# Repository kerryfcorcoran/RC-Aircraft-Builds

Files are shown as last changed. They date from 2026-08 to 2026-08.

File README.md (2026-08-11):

# RC Aircraft Builds

A public engineering archive for the design, construction, configuration, manufacturing, testing, and continued development of #teamcorc RC aircraft projects.

GitHub Pages:

https://teamcorc.github.io/RC-Aircraft-Builds/

This repository is intentionally organized as an engineering record rather than a conventional build blog. The goal is to preserve enough information to understand how each aircraft was actually constructed and configured at a particular point in its development.

---

## Repository Organization

Aircraft documentation follows this hierarchy:

```text
Manufacturer
└── Aircraft Model / Family
    └── Version
        └── Physical Build
```

This keeps different manufacturers, aircraft families, design revisions, and physical aircraft isolated from one another.

Current manufacturer areas include:

- Flightory
- Eclipson
- Titan Dynamics
- Additional manufacturers may be added as projects begin.

Example:

```text
aircraft/
├── flightory/
│   ├── stallion/
│   │   ├── references/
│   │   ├── v1/
│   │   │   └── build-01/
│   │   └── v2/
│   │       └── build-01/
│   ├── super-stingray-vtol/
│   ├── talon-1400/
│   └── stork/
├── eclipson/
└── titan-dynamics/
```

---

## Build-Level Engineering Records

A physical build can contain some or all of the following:

```text
build-01/
├── components/
├── assembly-wiring/
├── ardupilot/
├── flight-testing/
├── engineering/
├── media/
├── downloads/
└── printing/
```

Not every aircraft or build will contain every section. Documentation reflects information actually captured for that physical aircraft.

Typical records include:

- Exact installed hardware
- Component sources and manufacturer documentation
- Firmware
- ArduPilot PARAM files and configuration baselines
- Serial/UART mapping
- Servo and motor output assignments
- Wiring and power topology
- Assembly procedures and modifications
- 3D-printing/manufacturing settings
- Modified/custom STL files
- Ready-to-fly weight and battery configuration
- Flight-test objectives and observations
- Flight videos
- ArduPilot BIN logs
- Engineering analysis
- Configuration changes
- Known issues
- Lessons learned and build-specific gotchas

The intent is **reproducibility, configuration control, and traceability**.

---

# Flightory Stallion

The Stallion family currently contains two separate physical aircraft projects:

```text
Stallion
├── References
├── V1
│   └── Build 01
└── V2
    └── Build 01
```

## Stallion References

Family-level documentation is maintained under:

```text
aircraft/flightory/stallion/references/
```

This area contains:

- Official Flightory Stallion documentation
- Official Stallion VTOL documentation
- Matek F765-Wing references
- Builder Notes — Lessons Learned & Gotchas

Family-level references are intentionally separate from configuration records belonging to a specific physical aircraft.

Where a lesson applies only to one version/build, it should be explicitly identified as such.

---

## Stallion VTOL V1 — Build 01

V1 Build 01 is an existing aircraft undergoing VTOL flight development and testing.

The V1 record includes aircraft configuration, ArduPilot information, flight testing, engineering analysis, media, and downloadable configuration artifacts.

Detailed original manufacturing information was not captured during construction, so V1 Build 01 intentionally does **not** contain a 3D Printing & Manufacturing section.

Current hover/test configuration documented by the project:

- Ready-to-fly AUW: **2150 g**
- Hover/test battery: **4S 4200 mAh LiPo**
- Flight controller: **Matek F765-Wing**
- Firmware: **ArduPlane 4.6.3**

A separate 4S4P 14,000 mAh Li-ion battery is available as an endurance option but is not the current hover-test configuration.

---

## Stallion VTOL V2 — Build 01

V2 Build 01 is the newer Stallion build and contains substantially more detailed manufacturing and construction records.

Current implemented sections include:

- **3D Printing & Manufacturing**
- **Components**
- **Assembly & Wiring**
- **Downloads**
- **Builder Notes / reference material**

Additional sections will be populated as the build progresses.

### 3D Printing & Manufacturing

The detailed manufacturing report is located at:

```text
aircraft/flightory/stallion/v2/build-01/printing/
```

The report preserves part-level information such as:

- Printer
- Material
- Slicer
- Key slicer settings
- Print time
- Filament usage
- Part weight
- Status
- Reprints
- Build-specific findings

Current slicer baseline includes **OrcaSlicer v2.4.2**.

### Key V2 Manufacturing Findings

#### Thin-Wall Parts

The following parts can be sliced successfully in OrcaSlicer and do not require Cura:

- BOOM TAIL INSERT
- BOOM FUS INSERT
- BOOM FUS MOUNT

Required configuration:

- **Detect Thin Walls:** Enabled
- **Wall Generator:** Arachne

This supersedes the earlier interim finding that Cura was required for these parts.

#### X-Y Hole Compensation

For Stallion VTOL V2 Build 01, verify:

```text
X-Y Hole Compensation: 0.30 mm
```

This setting is part of the V2 Build 01 manufacturing baseline and should be checked when preparing applicable parts with holes or fitted hardware.

### Modified V-Tail Parts

Both VTail 1 components required modification during V2 Build 01 manufacturing:

- **V TAIL 1 L (modified)**
- **V TAIL 1 R (modified)**

The exact modified STL files are preserved under:

```text
aircraft/flightory/stallion/v2/build-01/downloads/
```

The corresponding part names in the 3D Printing & Manufacturing report link directly to these files.

The modified geometry is retained as a **build-specific configuration-controlled artifact** rather than replacing the original Flightory design reference.

### Components

V2 Build 01 component documentation is maintained under:

```text
aircraft/flightory/stallion/v2/build-01/components/
```

Current recorded hardware includes:

- **Torsion Springs — 4.5 mm, 120 Degree**

Component entries may include manufacturer documentation or product/source references where appropriate.

### Assembly & Wiring

V2 Build 01 assembly notes are maintained under:

```text
aircraft/flightory/stallion/v2/build-01/assembly-wiring/
```

A current build-specific wiring procedure is the V-tail servo extension:

- Cut the V-tail servo leads immediately behind the factory connector pins.
- Extend each lead by **400 mm** using matching servo wire.
- Maintain signal, positive-power, and ground conductor order/polarity.
- Insulate and strain-relieve the splices.
- Route the extended wiring through the carbon-fiber structure to the flight controller.

The 400 mm extension provides sufficient routing length without placing the servo wiring under unnecessary tension.

### Downloads

V2 Build 01 downloadable artifacts are stored under:

```text
aircraft/flightory/stallion/v2/build-01/downloads/
```

This area may contain:

- Modified/custom STL files
- PARAM/configuration files
- Engineering reports
- Other build-specific downloadable artifacts

Downloads should remain associated with the physical build to which they apply.

---

# Configuration Control Philosophy

Documentation should describe the aircraft **as it actually existed**, not simply the intended design.

When hardware, firmware, wiring, parameters, battery configuration, manufacturing geometry, or other significant items change, the engineering record should be updated accordingly.

Build-specific changes should not silently overwrite manufacturer references or records from another aircraft version.

Examples:

- A modified V2 STL belongs to the V2 Build 01 record.
- A V1 PARAM file belongs to V1 Build 01.
- A family-level Flightory manual belongs in Stallion References.
- A test-flight BIN should remain associated with the aircraft configuration that produced it.

---

# PARAM and Flight-Test Records

Meaningful ArduPilot configuration milestones should be preserved as named PARAM snapshots.

Examples include:

- Initial configuration
- Motor/servo verification
- First hover
- Roll/pitch tuning
- Yaw tuning
- First stable hover
- QLOITER preparation
- First successful QLOITER
- Pre-transition configuration
- Post-transition tuning

Meaningful flight tests should preserve the corresponding BIN log whenever possible.

BIN logs support quantitative evaluation of:

- PID tracking
- EKF behavior
- Yaw performance
- Motor saturation
- Magnetic interference
- RC input
- GPS behavior
- Battery behavior
- Flight-mode changes
- System messages

Video documents what the aircraft appeared to do; telemetry and BIN data help establish why it did it.

---

# Website

The repository is published as a static GitHub Pages project site.

Design goals include:

- Dark engineering-oriented theme
- Responsive layout
- Card-based navigation
- Clickable breadcrumb navigation
- Relative internal links wherever practical
- No server-side dependencies
- No unnecessary web frameworks

The repository remains a GitHub Pages **project site**:

```text
https://teamcorc.github.io/RC-Aircraft-Builds/
```

The repository should remain:

```text
teamcorc/RC-Aircraft-Builds
```

It should **not** be renamed to `teamcorc.github.io`.

---

# Documentation Standards

When adding or updating project records:

1. Preserve existing working content unless it is intentionally being revised.
2. Do not invent configuration, wiring, hardware, or test details.
3. Prefer official manufacturer documentation where available.
4. Keep different aircraft versions and physical builds isolated.
5. Preserve exact filenames for configuration-controlled artifacts.
6. Use relative internal links where practical.
7. Record actual test configuration, including AUW and battery when relevant.
8. Preserve meaningful PARAM and BIN records.
9. Treat modified files as build-specific artifacts unless their applicability has been independently established more broadly.
10. Add lessons learned and gotchas as they are discovered.

---

## Project Goal

The long-term goal of **RC Aircraft Builds** is to create a durable engineering archive that allows a future reader—or the builder months or years later—to determine:

- What was built
- Which hardware was installed
- How it was configured
- How it was manufactured
- What was changed
- What was tested
- What worked
- What did not work
- Why later decisions were made

That record is intended to remain useful long after an individual build or flight-test session is complete.

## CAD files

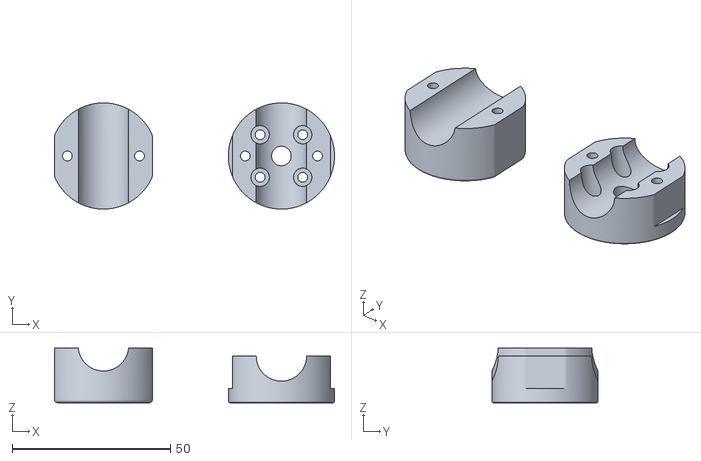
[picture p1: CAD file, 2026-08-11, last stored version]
Split Rear Motor Mount.stl
88.4 x 33.5 x 17.2

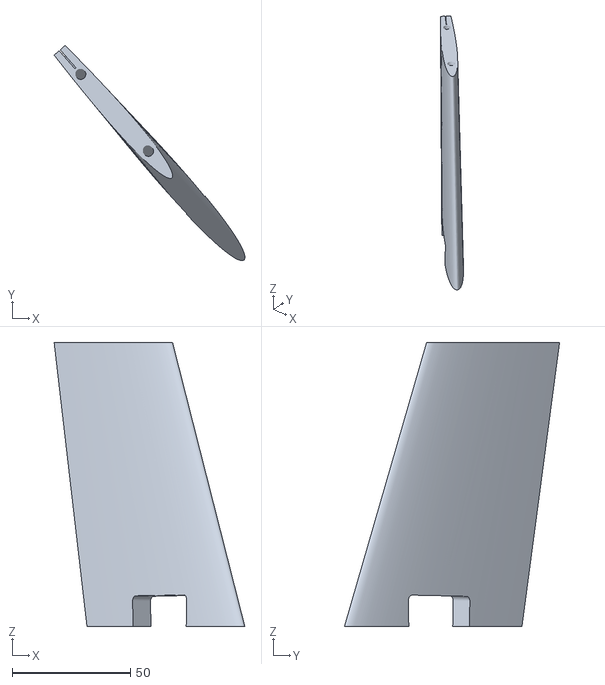
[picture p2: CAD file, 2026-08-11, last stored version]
VTail Right Modified.stl
80.6 x 90.9 x 120.0

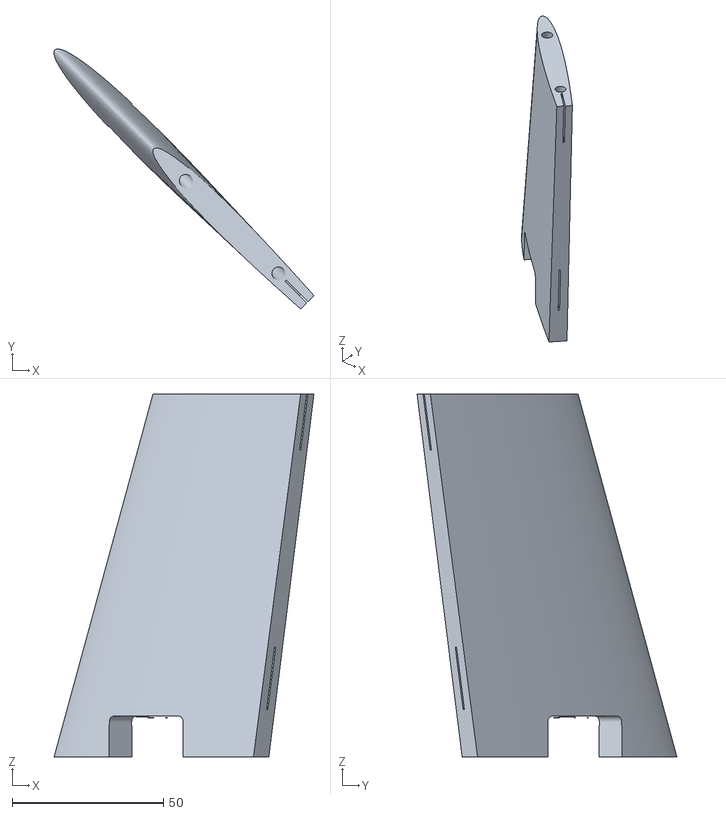
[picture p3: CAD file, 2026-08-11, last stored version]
VTail Left Modified.stl
85.9 x 85.9 x 120.0

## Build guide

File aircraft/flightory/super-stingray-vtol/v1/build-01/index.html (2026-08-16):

SUPER STINGRAY VTOL V1 — BUILD 01

Site HomeSuper Stingray VTOLV1

Home → Flightory → Super Stingray VTOL → V1 → Build 01

Physical Build 01

# Super Stingray VTOL V1 — Build 01

Build-specific engineering, manufacturing, configuration, and test documentation.

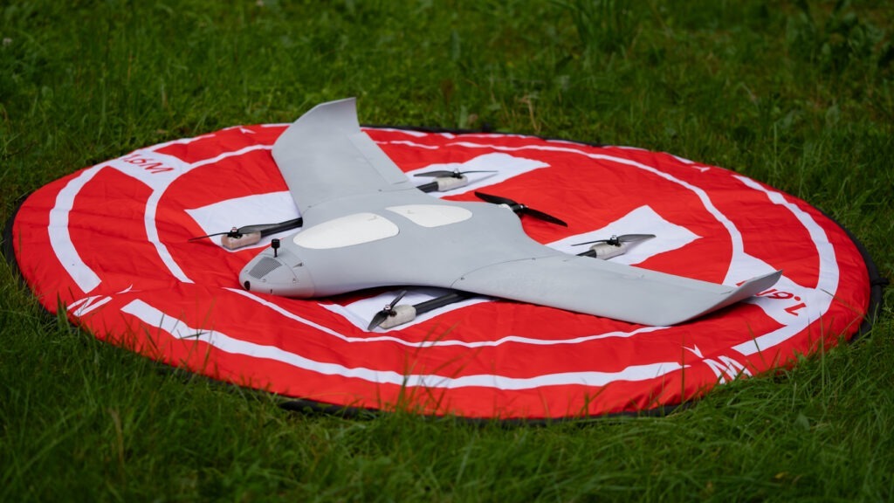
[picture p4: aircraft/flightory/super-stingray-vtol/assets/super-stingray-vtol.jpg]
Flightory Super Stingray VTOL aircraft


Image: Flightory

AVAILABLE

## 🖨️ 3D Printing & Manufacturing

Detailed part-level manufacturing report including printers, materials, slicer settings, weights, print times, filament consumption, and process notes.

Open Printing Report → AVAILABLE

## ✈️ Components

Installed and selected flight-control, propulsion-electronics, avionics, servos, batteries, and hardware.

Open Components →

## 🔧 Assembly & Wiring

Assembly procedures, wiring, connectors, and modifications.

SECTION TO BUILD

## 🛩️ ArduPilot

Firmware, parameters, configuration, calibration, and baselines.

SECTION TO BUILD

## 📊 Flight Testing

Ground tests, hover tests, flight tests, and video.

SECTION TO BUILD

AVAILABLE

## 📷 Media

Super Stingray and VTOL manuals, official Flightory documentation, and Matek F405-Wing reference material.

Open Media →

## 📁 Downloads

Build-specific downloadable artifacts.

SECTION TO BUILD

RC Aircraft Builds · Engineering Documentation

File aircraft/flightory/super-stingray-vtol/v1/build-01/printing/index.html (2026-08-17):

SUPER STINGRAY VTOL V1 — BUILD 01

RC Aircraft Builds Flightory Super Stingray VTOL V1 Build 01 3D Printing

RC Aircraft Builds → Flightory → Super Stingray VTOL → V1 → Build 01 → 3D Printing

#teamcorc · Super Stingray VTOL V1 Manufacturing

Flightory Super Stingray VTOL aircraft

Image: Flightory

# Detailed 3D Printing Report

Production report with executive summary, material usage, section-by-section part details, printer assignments, slicer settings, individual weights, print times, filament consumption, and reprint/process history.

37

Accepted printed components

689 g

Known accepted printed-part mass

254.210 m

Known filament consumed

73h 50m

Known recorded print time

Totals reflect accepted, recorded prints only.

Expand all Collapse all

### Material Summary

Material Group | Weight | Filament | Time
Overture PETG ↗ (https://overture3d.com/products/overture-petg) — Red | 260 g | 89.240 m | 9h 45m
eSun ePLA-LW ↗ (https://esun3dstore.com/products/epla-lw) — White | 429 g | 164.970 m | 64h 05m
Total | 689 g | 254.210 m | 73h 50m

Figures are printed-component mass only, not final empty weight or AUW.

### Current Process Baseline

Primary slicer: OrcaSlicer v2.4.2 ↗ (https://github.com/OrcaSlicer/OrcaSlicer/releases/tag/v2.4.2)

Nozzle: Creality Unicorn Hardened Steel Nozzle — 0.4 mm ↗ (https://store.creality.com/products/unicorn-quick-swap-nozzle-kit-for-k1c-ender-3-v3).

Structural PETG parts: 20% Cubic infill; generally 3 walls, with selected parts using 2 walls as recorded in the component tables. Supports used where required by geometry.

Lightweight ePLA-LW parts: Printed on either K1-Max White or K1-Max Orange as recorded in the component tables; generally 1 wall with 3% Gyroid infill and 45° orientation, with selected parts such as NOSE using 2 walls as recorded.

Boom / Tail Assembly 2 accepted line items · 46.0 g · 17.290 m · 1h 54m ▼

Part | Printer | Material | Slicer | Key Settings | Weight | Time | Filament | Status | Notes
BOOM MOUNT L | K1-Max Orange | Overture PETG ↗ (https://overture3d.com/products/overture-petg) Red | OrcaSlicer v2.4.2 | 3 walls; 20% Cubic; supports | 23 g | 1h 05m | 9.710 m | Complete
BOOM MOUNT R | K1-Max Orange | Overture PETG ↗ (https://overture3d.com/products/overture-petg) Red | OrcaSlicer v2.4.2 | 3 walls; 20% Cubic; no supports | 23 g | 49 m | 7.580 m | Complete | Fine without supports

Powertrain / Motor Mounts 3 line items · 9 accepted units · TOP ×4 · BOTTOM ×4 · MOTOR MOUNT ×1 complete ▼

Part | Qty | Printer | Material | Slicer | Key Settings | Weight | Time | Filament | Status | Notes
MOTOR MOUNT BOTTOM VTOL | 4 | K1-Max Orange | Overture PETG ↗ (https://overture3d.com/products/overture-petg) Red | OrcaSlicer v2.4.2 | 3 walls; 20% Cubic | 10 g | 24 m | 3.400 m | Complete | Per-unit figures
MOTOR MOUNT TOP VTOL | 4 | K1-Max Orange | Overture PETG ↗ (https://overture3d.com/products/overture-petg) Red | OrcaSlicer v2.4.2 | 3 walls; 20% Cubic | 8 g | 21 m | 2.740 m | Complete | Per-unit figures
MOTOR MOUNT | 1 | K1-Max Orange | Overture PETG ↗ (https://overture3d.com/products/overture-petg) Red | OrcaSlicer v2.4.2 | 2 walls; 20% Cubic | 6 g | 23 m | 1.960 m | Complete

Wings 14 accepted line items · 271.0 g · 99.720 m · 29h 22m ▼

Part | Printer | Material | Slicer | Key Settings | Weight | Time | Filament | Status | Notes
WING ROOT VTOL L | K1-Max Orange | Overture PETG ↗ (https://overture3d.com/products/overture-petg) Red | OrcaSlicer v2.4.2 | 3 walls; 20% Cubic; no supports | 47 g | 1h 15m | 15.670 m | Complete
WING ROOT VTOL R | K1-Max Orange | Overture PETG ↗ (https://overture3d.com/products/overture-petg) Red | OrcaSlicer v2.4.2 | 3 walls; 20% Cubic; no supports | 47 g | 1h 15m | 15.670 m | Complete
WING 2 L | K1-Max White | eSun ePLA-LW ↗ (https://esun3dstore.com/products/epla-lw) White | OrcaSlicer v2.4.2 | 1 wall; 3% Gyroid; 45° orientation | 24 g | 3h 08m | 8.590 m | Complete
WING 2 R VTOL | K1-Max White | eSun ePLA-LW ↗ (https://esun3dstore.com/products/epla-lw) White | OrcaSlicer v2.4.2 | 1 wall; 3% Gyroid; 45° orientation | 23 g | 2h 46m | 8.380 m | Complete
WINGTIP L 1 | K1-Max White | eSun ePLA-LW ↗ (https://esun3dstore.com/products/epla-lw) White | OrcaSlicer v2.4.2 | 1 wall; 3% Gyroid; 45° orientation | 11 g | 1h 26m | 4.210 m | Complete
WINGTIP L 2 | K1-Max White | eSun ePLA-LW ↗ (https://esun3dstore.com/products/epla-lw) White | OrcaSlicer v2.4.2 | 1 wall; 3% Gyroid; 45° orientation | 7 g | 56 m | 2.570 m | Complete
WINGTIP R 1 | K1-Max White | eSun ePLA-LW ↗ (https://esun3dstore.com/products/epla-lw) White | OrcaSlicer v2.4.2 | 1 wall; 3% Gyroid; 45° orientation | 12 g | 1h 26m | 4.220 m | Complete
WINGTIP R 2 | K1-Max Orange | eSun ePLA-LW ↗ (https://esun3dstore.com/products/epla-lw) White | OrcaSlicer v2.4.2 | 1 wall; 3% Gyroid; 45° orientation | 6 g | 56 m | 2.580 m | Complete
WING 1 L | K1-Max White | eSun ePLA-LW ↗ (https://esun3dstore.com/products/epla-lw) White | OrcaSlicer v2.4.2 | 1 wall; 3% Gyroid; 45° orientation | 39 g | 6h 07m | 15.170 m | Complete
WING 1 R | K1-Max Orange | eSun ePLA-LW ↗ (https://esun3dstore.com/products/epla-lw) White | OrcaSlicer v2.4.2 | 1 wall; 3% Gyroid; 45° orientation | 36 g | 6h 09m | 15.160 m | Complete
AILERON 1L VTOL | K1-Max Orange | eSun ePLA-LW ↗ (https://esun3dstore.com/products/epla-lw) White | OrcaSlicer v2.4.2 | 1 wall; 3% Gyroid; 45° orientation | 5 g | 54 m | 1.710 m | Complete
AILERON 1R VTOL | K1-Max White | eSun ePLA-LW ↗ (https://esun3dstore.com/products/epla-lw) White | OrcaSlicer v2.4.2 | 1 wall; 3% Gyroid; 45° orientation | 4 g | 54 m | 1.670 m | Complete
AILERON 2L VTOL | K1-Max Orange | eSun ePLA-LW ↗ (https://esun3dstore.com/products/epla-lw) White | OrcaSlicer v2.4.2 | 1 wall; 3% Gyroid; 45° orientation | 5 g | 1h 05m | 2.080 m | Complete
AILERON 2R VTOL | K1-Max White | eSun ePLA-LW ↗ (https://esun3dstore.com/products/epla-lw) White | OrcaSlicer v2.4.2 | 1 wall; 3% Gyroid; 45° orientation | 5 g | 1h 05m | 2.040 m | Complete

Fuselage 12 accepted line items · 294.0 g · 110.680 m · 39h 11m ▼

Part | Printer | Material | Slicer | Key Settings | Weight | Time | Filament | Status | Notes
FUS ROOT L | K1-Max Orange | Overture PETG ↗ (https://overture3d.com/products/overture-petg) Red | OrcaSlicer v2.4.2 | 3 walls; 20% Cubic | 9 g | 28 m | 2.870 m | Complete
FUS ROOT R | K1-Max Orange | Overture PETG ↗ (https://overture3d.com/products/overture-petg) Red | OrcaSlicer v2.4.2 | 3 walls; 20% Cubic | 8 g | 28 m | 2.880 m | Complete
BATTERY PAD | K1-Max Orange | Overture PETG ↗ (https://overture3d.com/products/overture-petg) Red | OrcaSlicer v2.4.2 | 2 walls; 20% Cubic | 20 g | 48 m | 6.640 m | Complete
FRONT REINFORCEMENT | K1-Max Orange | Overture PETG ↗ (https://overture3d.com/products/overture-petg) Red | OrcaSlicer v2.4.2 | 2 walls; 20% Cubic | 5 g | 14 m | 1.700 m | Complete
FUS 1 | K1-Max White | eSun ePLA-LW ↗ (https://esun3dstore.com/products/epla-lw) White | OrcaSlicer v2.4.2 | 1 wall; 3% Gyroid; 45° orientation | 33 g | 4h 21m | 12.120 m | Complete
FUS 4 L | K1-Max White | eSun ePLA-LW ↗ (https://esun3dstore.com/products/epla-lw) White | OrcaSlicer v2.4.2 | 1 wall; 3% Gyroid; 45° orientation; supports | 13 g | 2h 04m | 4.770 m | Complete | Uses supports, unlike other ePLA-LW parts
FUS 4 R | K1-Max White | eSun ePLA-LW ↗ (https://esun3dstore.com/products/epla-lw) White | OrcaSlicer v2.4.2 | 1 wall; 3% Gyroid; 45° orientation; supports | 13 g | 2h 05m | 4.860 m | Complete | Uses supports, unlike other ePLA-LW parts
NOSE | K1-Max White | eSun ePLA-LW ↗ (https://esun3dstore.com/products/epla-lw) White | OrcaSlicer v2.4.2 | 2 walls; 3% Gyroid; 45° orientation | 27 g | 3h 45m | 9.940 m | Complete | 2 walls — differs from 1-wall standard on other ePLA-LW parts
FUS 2 L | K1-Max White | eSun ePLA-LW ↗ (https://esun3dstore.com/products/epla-lw) White | OrcaSlicer v2.4.2 | 1 wall; 3% Gyroid; 45° orientation | 29 g | 4h 05m | 11.170 m | Complete
FUS 2 R | K1-Max Orange | eSun ePLA-LW ↗ (https://esun3dstore.com/products/epla-lw) White | OrcaSlicer v2.4.2 | 1 wall; 3% Gyroid; 45° orientation | 27 g | 4h 04m | 11.140 m | Complete
FUS 3 R | K1-Max Orange | eSun ePLA-LW ↗ (https://esun3dstore.com/products/epla-lw) White | OrcaSlicer v2.4.2 | 1 wall; 3% Gyroid; 45° orientation | 52 g | 8h 50m | 21.360 m | Complete
FUS 3 L | K1-Max White | eSun ePLA-LW ↗ (https://esun3dstore.com/products/epla-lw) White | OrcaSlicer v2.4.2 | 1 wall; 3% Gyroid; 45° orientation | 58 g | 7h 59m | 21.230 m | Complete

Manufacturing Baseline ▼

## Manufacturing Baseline

37 accepted components · 689 g known mass · 254.210 m known filament · 73h 50m known printing

Boom/tail hardware, powertrain motor mounts (MOTOR MOUNT TOP VTOL ×4, MOTOR MOUNT BOTTOM VTOL ×4, MOTOR MOUNT ×1), wing roots, WING 1 L/R, WING 2 L/R, WINGTIP L 1/2, WINGTIP R 1/2, AILERON 1L/1R/2L/2R VTOL, and fuselage hardware (FUS ROOT L/R, BATTERY PAD, FRONT REINFORCEMENT, FUS 1, FUS 4 L, FUS 4 R, NOSE, FUS 2 L/R, FUS 3 L/R) all complete. All recorded completed parts printed clean without supports except BOOM MOUNT L, FUS 4 L, and FUS 4 R (supports). WING 1 L/R, WING 2 L/R, all wingtips and ailerons, and the FUS 1/2/3/4 series plus NOSE run the second process: eSun ePLA-LW at 1 wall / 3% Gyroid / 45° orientation (NOSE uses 2 walls), printed on K1-Max White or K1-Max Orange as recorded in the component tables.

Super Stingray VTOL V1 — Detailed 3D Printing Manufacturing Report · Slicing baseline: OrcaSlicer v2.4.2 (https://github.com/OrcaSlicer/OrcaSlicer/releases/tag/v2.4.2)

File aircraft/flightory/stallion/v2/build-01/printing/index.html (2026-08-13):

STALLION VTOL V2 — BUILD 01

RC Aircraft Builds Flightory Stallion V2 Build 01 3D Printing

RC Aircraft Builds → Flightory → Stallion → V2 → Build 01 → 3D Printing

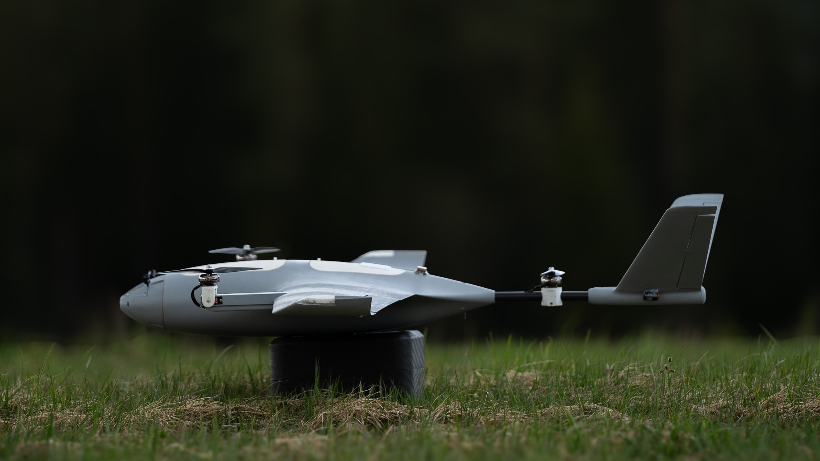
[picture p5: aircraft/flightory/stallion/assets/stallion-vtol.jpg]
Flightory Stallion VTOL aircraft
#teamcorc · Stallion VTOL V2 Manufacturing 

Image: Flightory

# Detailed 3D Printing Report

Refreshed production report with executive summary, material usage, section-by-section part details, printer assignments, slicer settings, individual weights, print times, filament consumption, and reprint/process history.

66

Accepted printed components

883 g*

Known accepted printed-part mass

412.090 m*

Known filament consumed

91h 08m*

Known recorded print time

* Split Rear Motor Mount is accepted, but its weight, print time, and filament usage have not yet been recorded; aggregate known totals exclude those values.

Expand all Collapse all

### Material Summary

Material Group | Weight | Filament | Time
Polymaker PolyLite LW-PLA ↗ (https://us.polymaker.com/products/polylite-lw-pla) — Gray / White | 650 g | 321.225 m* | 65 h 54 m*
Overture PETG ↗ (https://overture3d.com/products/overture-petg) — White / Red | 232 g* | 90.516 m* | 25 h 07 m*
Generic PLA — Transparent | 1 g | 0.349 m | 7 m
Total | 883 g* | 412.090 m* | 91 h 08 m*

The 895 g figure is printed-component mass only, not final empty weight or AUW. *Tail 1 print time and filament were not recorded, so filament/time totals are known minimums.

### Current Process Baseline

Primary slicer: OrcaSlicer v2.4.2 ↗ (https://github.com/OrcaSlicer/OrcaSlicer/releases/tag/v2.4.2)

Nozzle: Creality Unicorn Hardened Steel Nozzle — 0.4 mm ↗ (https://store.creality.com/products/unicorn-quick-swap-nozzle-kit-for-k1c-ender-3-v3).

LW-PLA aerodynamic parts: primarily OrcaSlicer with 1 wall and low-density Gyroid or Lateral Lattice infill.

Structural PETG: generally 3 walls with 20% Grid or Cubic depending on part.

Thin-wall boom parts: OrcaSlicer works correctly when Detect Thin Walls is enabled and Wall Generator = Arachne.

Transparent LED covers: Detect Thin Walls enabled.

Key Manufacturing Findings Updated to reflect the latest validated slicer configuration ▼

### OrcaSlicer v2.4.2 ↗ (https://github.com/OrcaSlicer/OrcaSlicer/releases/tag/v2.4.2) — Thin-Wall Configuration

BOOM TAIL INSERT, BOOM FUS INSERT, and BOOM FUS MOUNT do not require Cura. They can be sliced successfully in OrcaSlicer with:

- Detect Thin Walls: Enabled
- Wall Generator: Arachne

This supersedes the earlier interim note that Cura was required.

### X-Y Hole Compensation

For Stallion VTOL V2 Build 01, ensure X-Y Hole Compensation is set to 0.30 mm in OrcaSlicer before slicing applicable parts.

This is part of the V2 Build 01 manufacturing baseline and should be checked when preparing parts with holes or fitted hardware.

### Replacement / Reprint Notes

- Custom rear motor mount: original split; replacement uses separate Top-Rear-Motor-Mount and Bottom-Rear-Motor-Mount parts.
- TAIL 1: accepted as final part (18 g); print time and filament were not recorded.
- Wing Lock Assembly: Neptune 2S Base + Front L/R + Rear L/R assembly accepted as final.

Wings 10 accepted line items · 219.0 g recorded · 110.919 m recorded · 22h 16m recorded ▼

Part | Printer | Material | Slicer | Key Settings | Weight | Time | Filament | Status | Notes
WING 3 R | K1 Max Orange | Polymaker PolyLite LW-PLA ↗ (https://us.polymaker.com/products/polylite-lw-pla) Gray | OrcaSlicer | 1 wall; 3% Lateral Lattice; 45° | 23 g | 2h 15m | 11.300 m | Complete | Minimal post cleanup
WING 3 L | K1 Max White | Polymaker PolyLite LW-PLA ↗ (https://us.polymaker.com/products/polylite-lw-pla) Gray | OrcaSlicer | 1 wall; 3% Lateral Lattice; 45° | 23 g | 2h 15m | 11.300 m | Complete
WING 1R VTOL | K1 Max Orange | Polymaker PolyLite LW-PLA ↗ (https://us.polymaker.com/products/polylite-lw-pla) Gray | OrcaSlicer | 1 wall; 3% Lateral Lattice; 45° | 45 g | 4h 29m | 22.400 m | Complete
WING 1L VTOL | K1 Max White | Polymaker PolyLite LW-PLA ↗ (https://us.polymaker.com/products/polylite-lw-pla) Gray | OrcaSlicer | 1 wall; 3% Lateral Lattice; 45°; supports | 45 g | 4h 38m | 23.050 m | Complete | Support test came out very clean
WING 2L VTOL | K1 Max White | Polymaker PolyLite LW-PLA ↗ (https://us.polymaker.com/products/polylite-lw-pla) Gray | OrcaSlicer | 1 wall; 3% Lateral Lattice; 45°; tree support auto | 26 g | 2h 50m | 14.000 m | Complete
WING 2R VTOL | K1 Max Orange | Polymaker PolyLite LW-PLA ↗ (https://us.polymaker.com/products/polylite-lw-pla) Gray | OrcaSlicer | 1 wall; 3% Lateral Lattice; 45°; tree support auto | 27 g | 2h 51m | 14.040 m | Complete
WINGTIP R LED | K1 Max Orange | Polymaker PolyLite LW-PLA ↗ (https://us.polymaker.com/products/polylite-lw-pla) Gray | OrcaSlicer | 1 wall; 3% Lateral Lattice; 45° | 15 g | 1h 25m | 7.240 m | Complete
WINGTIP L LED | K1 Max Orange | Polymaker PolyLite LW-PLA ↗ (https://us.polymaker.com/products/polylite-lw-pla) Gray | OrcaSlicer | 1 wall; 3% Lateral Lattice; 45° | 14 g | 1h 26m | 7.240 m | Complete
WING LED COVER L | K1 Max White | Generic PLA Transparent | OrcaSlicer | Detect Thin Walls | 0.5 g | 3.5 min | 0.174 m | Complete | Printed as shared L/R job; job total 7 min / 0.349 m
WING LED COVER R | K1 Max White | Generic PLA Transparent | OrcaSlicer | Detect Thin Walls | 0.5 g | 3.5 min | 0.174 m | Complete | Printed as shared L/R job; job total 7 min / 0.349 m

Fuselage 11 accepted line items · 306.0 g recorded · 153.116 m recorded · 29h 27m recorded ▼

Part | Printer | Material | Slicer | Key Settings | Weight | Time | Filament | Status | Notes
FUS 1 | K1 Max White | Polymaker PolyLite LW-PLA ↗ (https://us.polymaker.com/products/polylite-lw-pla) Gray | OrcaSlicer | 1 wall; 3% Gyroid; 0° | 33 g | 3h 09m | 16.410 m | Complete
FUS 2 | K1 Max White | Polymaker PolyLite LW-PLA ↗ (https://us.polymaker.com/products/polylite-lw-pla) Gray | OrcaSlicer | 1 wall; 3% Gyroid; 45°; support enabled | 51 g | 4h 45m | 25.440 m | Complete
FUS 3 | K1 Max Orange | Polymaker PolyLite LW-PLA ↗ (https://us.polymaker.com/products/polylite-lw-pla) Gray | OrcaSlicer | 1 wall; 3% Gyroid; 45° | 51 g | 4h 54m | 25.660 m | Complete
FUS 4 | K1 Max White | Polymaker PolyLite LW-PLA ↗ (https://us.polymaker.com/products/polylite-lw-pla) Gray | OrcaSlicer | 1 wall; 3% Gyroid; 45° | 70 g | 7h 02m | 37.726 m | Complete
FUS 5 | K1 Max Orange | Polymaker PolyLite LW-PLA ↗ (https://us.polymaker.com/products/polylite-lw-pla) Gray | OrcaSlicer | 1 wall; 3% Gyroid; 45° | 39 g | 3h 36m | 18.720 m | Complete
HATCH FRONT 1 | K1 Max White | Polymaker PolyLite LW-PLA ↗ (https://us.polymaker.com/products/polylite-lw-pla) White | OrcaSlicer | 1 wall; 3% Gyroid; 45° | 7 g | 48m | 3.320 m | Complete
HATCH FRONT 2 | K1 Max White | Polymaker PolyLite LW-PLA ↗ (https://us.polymaker.com/products/polylite-lw-pla) White | OrcaSlicer | 1 wall; 3% Gyroid; 45° | 8 g | 49m | 3.670 m | Complete
HATCH REAR 1 | K1 Max Orange | Polymaker PolyLite LW-PLA ↗ (https://us.polymaker.com/products/polylite-lw-pla) White | OrcaSlicer | 1 wall; 3% Gyroid; 45° | 7 g | 43m | 3.270 m | Complete | Printer assignment corrected from White to Orange
HATCH REAR 2 | K1 Max Orange | Polymaker PolyLite LW-PLA ↗ (https://us.polymaker.com/products/polylite-lw-pla) White | OrcaSlicer | 1 wall; 3% Gyroid; 45° | 6 g | 42m | 2.810 m | Complete
NOSE | K1 Max Orange | Polymaker PolyLite LW-PLA ↗ (https://us.polymaker.com/products/polylite-lw-pla) Gray | OrcaSlicer | 2 walls; 3% Gyroid; 45° | 29 g | 2h 24m | 13.610 m | Complete | Weight supplied later
NOSE TOP | K1 Max White | Polymaker PolyLite LW-PLA ↗ (https://us.polymaker.com/products/polylite-lw-pla) White | OrcaSlicer | 2 walls; 3% Gyroid; 45° | 5 g | 35m | 2.480 m | Complete

Tail & Control Surfaces 16 accepted line items · 108.0 g recorded · 57.539 m recorded · 14h 02m recorded ▼

Part | Printer | Material | Slicer | Key Settings | Weight | Time | Filament | Status | Notes
V TAIL 1 L (modified) ⬇ | K1 Max Orange | Polymaker PolyLite LW-PLA ↗ (https://us.polymaker.com/products/polylite-lw-pla) Gray | OrcaSlicer | 4% Gyroid; 45°; support | 14 g | 1h 32m | 7.220 m | Complete | Modified for V2 Build 01. Click part name to download the modified STL.
V TAIL 1 R (modified) ⬇ | K1 Max White | Polymaker PolyLite LW-PLA ↗ (https://us.polymaker.com/products/polylite-lw-pla) Gray | OrcaSlicer | 4% Gyroid; 45°; support | 12 g | 1h 32m | 7.210 m | Complete | Modified for V2 Build 01. Click part name to download the modified STL.
V TAIL 2 L | K1 Max Orange | Polymaker PolyLite LW-PLA ↗ (https://us.polymaker.com/products/polylite-lw-pla) Gray | OrcaSlicer | 4% Gyroid; 45°; support | 9 g | 1h 07m | 4.700 m | Complete
V TAIL 2 R | K1 Max White | Polymaker PolyLite LW-PLA ↗ (https://us.polymaker.com/products/polylite-lw-pla) Gray | OrcaSlicer | 4% Gyroid; 45°; support | 8 g | 1h 07m | 4.710 m | Complete
V TAIL TIP L | K1 Max Orange | Polymaker PolyLite LW-PLA ↗ (https://us.polymaker.com/products/polylite-lw-pla) Gray | OrcaSlicer | 4% Gyroid; 45° | 0.5 g | 13m | 0.877 m | Complete
V TAIL TIP R | K1 Max White | Polymaker PolyLite LW-PLA ↗ (https://us.polymaker.com/products/polylite-lw-pla) Gray | OrcaSlicer | 4% Gyroid; 45° | 0.5 g | 13m | 0.852 m | Complete
RUDDER 1L | K1 Max Orange | Polymaker PolyLite LW-PLA ↗ (https://us.polymaker.com/products/polylite-lw-pla) Gray | OrcaSlicer | 4% Gyroid; 45° | 6 g | 52m | 2.570 m | Complete
RUDDER 1R | K1 Max White | Polymaker PolyLite LW-PLA ↗ (https://us.polymaker.com/products/polylite-lw-pla) Gray | OrcaSlicer | 4% Gyroid; 45° | 6 g | 52m | 2.570 m | Complete
RUDDER 2L | K1 Max Orange | Polymaker PolyLite LW-PLA ↗ (https://us.polymaker.com/products/polylite-lw-pla) Gray | OrcaSlicer | 4% Gyroid; 45° | 3 g | 38m | 1.660 m | Complete
RUDDER 2R | K1 Max White | Polymaker PolyLite LW-PLA ↗ (https://us.polymaker.com/products/polylite-lw-pla) Gray | OrcaSlicer | 4% Gyroid; 45° | 3 g | 38m | 1.660 m | Complete
TAIL 1 | K1 Max White | Polymaker PolyLite LW-PLA ↗ (https://us.polymaker.com/products/polylite-lw-pla) Gray | OrcaSlicer | 2 walls; 3% Gyroid | 18 g | — | — | Complete | Accepted final part; print time and filament were not recorded
TAIL 2 | K1 Max Orange | Polymaker PolyLite LW-PLA ↗ (https://us.polymaker.com/products/polylite-lw-pla) Gray | OrcaSlicer | 2 walls; 3% Gyroid; painted tree support | 18 g | 1h 38m | 8.870 m | Complete
TAIL 3 | Not recorded | Not recorded | Not recorded | | 2 g | 14m | 1.190 m | Complete
AILERON 1L | K1 Max Orange | Polymaker PolyLite LW-PLA ↗ (https://us.polymaker.com/products/polylite-lw-pla) Gray | OrcaSlicer | 1 wall; 3% Gyroid; 45° | 7 g | 50m | 3.300 m | Complete
AILERON 1R | K1 Max White | Polymaker PolyLite LW-PLA ↗ (https://us.polymaker.com/products/polylite-lw-pla) Gray | OrcaSlicer | 1 wall; 3% Gyroid; 45° | 6 g | 51m | 3.300 m | Complete
AILERON 2L | K1 Max Orange | Polymaker PolyLite LW-PLA ↗ (https://us.polymaker.com/products/polylite-lw-pla) Gray | OrcaSlicer | 1 wall; 3% Gyroid; 45° | 7 g | 52m | 3.410 m | Complete
AILERON 2R | K1 Max White | Polymaker PolyLite LW-PLA ↗ (https://us.polymaker.com/products/polylite-lw-pla) Gray | OrcaSlicer | 1 wall; 3% Gyroid; 45° | 6 g | 53m | 3.440 m | Complete

Structural PETG 17 accepted line items · 225.0 g recorded · 88.136 m recorded · 24h 43m recorded ▼

Part | Printer | Material | Slicer | Key Settings | Weight | Time | Filament | Status | Notes
BOOM L | Elegoo Neptune 2S | Overture PETG ↗ (https://overture3d.com/products/overture-petg) White | OrcaSlicer / OctoPrint workflow | 3 walls; 4 top/bottom; 20% Cubic; 45° | 45 g | 5h 16m | 18.520 m | Complete
BOOM R | Elegoo Neptune 2S | Overture PETG ↗ (https://overture3d.com/products/overture-petg) White | OrcaSlicer / OctoPrint workflow | 3 walls; 4 top/bottom; 20% Cubic; 45° | 44 g | 5h 16m | 18.520 m | Complete
FUS ROOT L | Elegoo Neptune 2S | Overture PETG ↗ (https://overture3d.com/products/overture-petg) White | OrcaSlicer / OctoPrint workflow | 3 walls; 20% Grid; support | 9 g | 1h 07m | 3.320 m | Complete
FUS ROOT R | Elegoo Neptune 2S | Overture PETG ↗ (https://overture3d.com/products/overture-petg) White | OrcaSlicer / OctoPrint workflow | 3 walls; 20% Grid; support | 9 g | 1h 07m | 3.320 m | Complete
WING ROOT L | K1 Max Orange | Overture PETG ↗ (https://overture3d.com/products/overture-petg) White | OrcaSlicer | 3 walls; 20% Grid; 45° | 10 g | 41m | 3.790 m | Complete
WING ROOT R | K1 Max White | Overture PETG ↗ (https://overture3d.com/products/overture-petg) White | OrcaSlicer | 3 walls; 20% Grid; 45° | 11 g | 38m | 4.140 m | Complete | Weight corrected from initial 1 g entry
FRONT REINFORCEMENT | K1 Max Orange | Overture PETG ↗ (https://overture3d.com/products/overture-petg) White | OrcaSlicer | 3 walls; 20% Grid | 3 g | 8m | 0.966 m | Complete
MOTOR MOUNT TAIL | K1 Max White | Overture PETG ↗ (https://overture3d.com/products/overture-petg) White | OrcaSlicer | 3 walls; 20% Grid | 12 g | 42m | 4.380 m | Complete
MOTOR MOUNT FRONT ×2 | K1 Max Orange | Overture PETG ↗ (https://overture3d.com/products/overture-petg) White | OrcaSlicer | 3 walls; 20% Grid | 12 g | 51m | 4.580 m | Complete | 12 g is combined pair weight
SERVO COVER L + R | K1 Max White | Overture PETG ↗ (https://overture3d.com/products/overture-petg) White | OrcaSlicer | 3 walls; 20% Grid | 7 g | 41m | 5.390 m | Complete | Combined job / combined weight
BATTERY PAD | K1 Max Orange | Overture PETG ↗ (https://overture3d.com/products/overture-petg) White | OrcaSlicer | 3 walls; 20% Grid | 9 g | 24m | 3.240 m | Complete
BOOM TAIL INSERT | K1 Max White | Overture PETG ↗ (https://overture3d.com/products/overture-petg) White | OrcaSlicer | 3 walls; 20% Grid; Detect Thin Walls; Arachne | 12 g | 2h 46m | 3.990 m | Complete | Initially problematic; OrcaSlicer works with Detect Thin Walls + Arachne
BOOM FUS INSERT | K1 Max White | Overture PETG ↗ (https://overture3d.com/products/overture-petg) White | OrcaSlicer | 3 walls; 20% Grid; Detect Thin Walls; Arachne | 10 g | 1h 54m | 3.400 m | Complete | OrcaSlicer works with Detect Thin Walls + Arachne
BOOM FUS MOUNT | K1 Max White | Overture PETG ↗ (https://overture3d.com/products/overture-petg) White | OrcaSlicer | 3 walls; 20% Grid; Detect Thin Walls; Arachne | 15 g | 1h 56m | 5.150 m | Complete | OrcaSlicer works with Detect Thin Walls + Arachne
BOOM KNOB | K1 Max Orange | Overture PETG ↗ (https://overture3d.com/products/overture-petg) White | OrcaSlicer | 3 walls; 20% Grid | 5 g | 35m | 1.600 m | Complete
Split Rear Motor Mount ⬇ | K1 Max Orange | Overture PETG ↗ (https://overture3d.com/products/overture-petg) White | OrcaSlicer | 20% Gyroid | — | — | — | Complete | Modified for V2 Build 01. Replaces the separate Top and Bottom Rear Motor Mount parts. Click the part name to download the STL.

Wing Lock Hardware 4 accepted line items · 19.0 g recorded · 6.210 m recorded · 1h 35m recorded ▼

Part | Printer | Material | Slicer | Key Settings | Weight | Time | Filament | Status | Notes
Wing Lock Assembly (Base + Front L/R + Rear L/R) | Elegoo Neptune 2S | Overture PETG ↗ (https://overture3d.com/products/overture-petg) Red | OrcaSlicer / OctoPrint workflow | 3 walls; 20% Grid; 45° | 10 g | 1h 07m | 3.310 m | Complete | Accepted final assembly
LOCK 1 | K1 Max Orange | Overture PETG ↗ (https://overture3d.com/products/overture-petg) Red | OrcaSlicer | 3 walls; 20% Grid | — | — | — | Complete | Part of shared 4-part job
LOCK 2 | K1 Max Orange | Overture PETG ↗ (https://overture3d.com/products/overture-petg) Red | OrcaSlicer | 3 walls; 20% Grid | — | — | — | Complete | Part of shared 4-part job
LOCK SPRING ×2 | K1 Max Orange | Overture PETG ↗ (https://overture3d.com/products/overture-petg) Red | OrcaSlicer | 3 walls; 20% Grid | 9 g | 28m | 2.900 m | Complete | 9 g / 28 min / 2.90 m are totals for LOCK 1 + LOCK 2 + two springs

Open / Non-Final Items ▼

Item | Status | Disposition
TAIL 1 | Accepted | 18 g. Final part accepted; print time and filament were not recorded.
Wing Lock Assembly (Neptune 2S) | Accepted | Base + Front L/R + Rear L/R accepted as final assembly. 10 g, 1h 07m, 3.31 m.

Manufacturing Baseline ▼

## Manufacturing Baseline

66 accepted components · 883 g known mass* · 412.090 m known filament* · 91 h 08 m known printing*

Equivalent known cumulative printer time: 3 days 19 hours 08 minutes. Tail 1 print time/filament and Split Rear Motor Mount weight/time/filament remain unrecorded.

Stallion VTOL V2 — Detailed 3D Printing Manufacturing Report · Slicing baseline: OrcaSlicer v2.4.2 (https://github.com/OrcaSlicer/OrcaSlicer/releases/tag/v2.4.2)

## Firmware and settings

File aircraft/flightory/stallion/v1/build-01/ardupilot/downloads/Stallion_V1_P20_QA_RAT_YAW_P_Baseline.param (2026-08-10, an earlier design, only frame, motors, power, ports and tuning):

BATT_AMP_OFFSET,0
BATT_AMP_PERVLT,40
BATT_ARM_MAH,0
BATT_ARM_VOLT,0
BATT_CAPACITY,4200
BATT_CRT_MAH,0
BATT_CRT_VOLT,0
BATT_CURR_PIN,13
BATT_FS_CRT_ACT,0
BATT_FS_LOW_ACT,0
BATT_FS_VOLTSRC,0
BATT_LOW_MAH,0
BATT_LOW_TIMER,10
BATT_LOW_VOLT,0
BATT_MONITOR,4
BATT_OPTIONS,0
BATT_SERIAL_NUM,-1
BATT_VLT_OFFSET,0
BATT_VOLT_MULT,10.89
BATT_VOLT_PIN,12
BATT_WATT_MAX,0
BATT2_MONITOR,0
BATT3_MONITOR,0
BATT4_MONITOR,0
BATT5_MONITOR,0
BATT6_MONITOR,0
BATT7_MONITOR,0
BATT8_MONITOR,0
BATT9_MONITOR,0
FLTMODE_CH,5
FLTMODE_GCSBLOCK,0
FLTMODE1,17
FLTMODE2,17
FLTMODE3,5
FLTMODE4,5
FLTMODE5,0
FLTMODE6,0
INS_GYRO_FILTER,20
INS_HNTCH_ENABLE,0
Q_A_ACCEL_P_MAX,40000
Q_A_ACCEL_R_MAX,40000
Q_A_ACCEL_Y_MAX,10000
Q_A_ANG_LIM_TC,1
Q_A_ANG_PIT_P,5
Q_A_ANG_RLL_P,4.5
Q_A_ANG_YAW_P,4.5
Q_A_ANGLE_BOOST,1
Q_A_INPUT_TC,0.2
Q_A_LAND_P_MULT,1
Q_A_LAND_R_MULT,1
Q_A_LAND_Y_MULT,1
Q_A_RAT_PIT_D,0.0131
Q_A_RAT_PIT_D_FF,0
Q_A_RAT_PIT_FF,0
Q_A_RAT_PIT_FLTD,10
Q_A_RAT_PIT_FLTE,0
Q_A_RAT_PIT_FLTT,20
Q_A_RAT_PIT_I,0.556
Q_A_RAT_PIT_IMAX,0.5
Q_A_RAT_PIT_NEF,0
Q_A_RAT_PIT_NTF,0
Q_A_RAT_PIT_P,0.293
Q_A_RAT_PIT_PDMX,0
Q_A_RAT_PIT_SMAX,50
Q_A_RAT_RLL_D,0.00357
Q_A_RAT_RLL_D_FF,0
Q_A_RAT_RLL_FF,0
Q_A_RAT_RLL_FLTD,10
Q_A_RAT_RLL_FLTE,0
Q_A_RAT_RLL_FLTT,20
Q_A_RAT_RLL_I,0.23
Q_A_RAT_RLL_IMAX,0.5
Q_A_RAT_RLL_NEF,0
Q_A_RAT_RLL_NTF,0
Q_A_RAT_RLL_P,0.23
Q_A_RAT_RLL_PDMX,0
Q_A_RAT_RLL_SMAX,50
Q_A_RAT_YAW_D,0
Q_A_RAT_YAW_D_FF,0
Q_A_RAT_YAW_FF,0
Q_A_RAT_YAW_FLTD,20
Q_A_RAT_YAW_FLTE,2.5
Q_A_RAT_YAW_FLTT,20
Q_A_RAT_YAW_I,0.018
Q_A_RAT_YAW_IMAX,0.5
Q_A_RAT_YAW_NEF,0
Q_A_RAT_YAW_NTF,0
Q_A_RAT_YAW_P,0.22
Q_A_RAT_YAW_PDMX,0
Q_A_RAT_YAW_SMAX,50
Q_A_RATE_FF_ENAB,1
Q_A_RATE_P_MAX,75
Q_A_RATE_R_MAX,75
Q_A_RATE_Y_MAX,75
Q_A_SLEW_YAW,6000
Q_A_THR_G_BOOST,0
Q_A_THR_MIX_MAN,0.1
Q_A_THR_MIX_MAX,0.5
Q_A_THR_MIX_MIN,0.1
Q_M_BAT_CURR_MAX,0
Q_M_BAT_CURR_TC,5
Q_M_BAT_IDX,0
Q_M_BAT_VOLT_MAX,16.8
Q_M_BAT_VOLT_MIN,13.2
Q_M_BOOST_SCALE,0
Q_M_HOVER_LEARN,2
Q_M_OPTIONS,0
Q_M_PWM_MAX,2000
Q_M_PWM_MIN,1000
Q_M_PWM_TYPE,6
Q_M_SAFE_DISARM,0
Q_M_SAFE_TIME,1
Q_M_SLEW_DN_TIME,0
Q_M_SLEW_UP_TIME,0
Q_M_SPIN_ARM,0.1
Q_M_SPIN_MAX,0.95
Q_M_SPIN_MIN,0.15
Q_M_SPOOL_TIM_DN,0
Q_M_SPOOL_TIME,0.25
Q_M_THST_EXPO,0.65
Q_M_THST_HOVER,0.35
Q_M_YAW_HEADROOM,200
Q_M_YAW_SV_ANGLE,30
SERIAL0_BAUD,115
SERIAL0_PROTOCOL,2
SERIAL1_BAUD,420
SERIAL1_OPTIONS,0
SERIAL1_PROTOCOL,-1
SERIAL2_BAUD,57
SERIAL2_OPTIONS,0
SERIAL2_PROTOCOL,2
SERIAL3_BAUD,115
SERIAL3_OPTIONS,0
SERIAL3_PROTOCOL,5
SERIAL4_BAUD,230
SERIAL4_OPTIONS,0
SERIAL4_PROTOCOL,-1
SERIAL5_BAUD,57
SERIAL5_OPTIONS,0
SERIAL5_PROTOCOL,-1
SERIAL6_BAUD,420
SERIAL6_OPTIONS,0
SERIAL6_PROTOCOL,23
SERIAL7_BAUD,420
SERIAL7_OPTIONS,0
SERIAL7_PROTOCOL,-1
SERIAL8_BAUD,57
SERIAL8_OPTIONS,0
SERIAL8_PROTOCOL,-1
SERVO1_FUNCTION,4
SERVO1_MAX,1900
SERVO1_MIN,1100
SERVO1_REVERSED,1
SERVO1_TRIM,1500
SERVO2_FUNCTION,4
SERVO2_MAX,1900
SERVO2_MIN,1100
SERVO2_REVERSED,1
SERVO2_TRIM,1500
SERVO3_FUNCTION,79
SERVO3_MAX,1900
SERVO3_MIN,1100
SERVO3_REVERSED,1
SERVO3_TRIM,1500
SERVO4_FUNCTION,80
SERVO4_MAX,1900
SERVO4_MIN,1100
SERVO4_REVERSED,0
SERVO4_TRIM,1500
SERVO5_FUNCTION,0
SERVO5_MAX,1900
SERVO5_MIN,1100
SERVO5_REVERSED,0
SERVO5_TRIM,1500
SERVO6_FUNCTION,0
SERVO6_MAX,1900
SERVO6_MIN,1100
SERVO6_REVERSED,0
SERVO6_TRIM,1500
SERVO7_FUNCTION,33
SERVO7_MAX,2000
SERVO7_MIN,1000
SERVO7_REVERSED,0
SERVO7_TRIM,1000
SERVO8_FUNCTION,34
SERVO8_MAX,2000
SERVO8_MIN,1000
SERVO8_REVERSED,0
SERVO8_TRIM,1000
SERVO9_FUNCTION,36
SERVO9_MAX,2000
SERVO9_MIN,1000
SERVO9_REVERSED,0
SERVO9_TRIM,1000

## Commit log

2026-08-09 Add files via upload
    Add Stallion VTOL v2 Printing report.
2026-08-09 Add README for Stallion VTOL V2 project documentation
    This README provides comprehensive documentation for the Stallion VTOL V2 aircraft project, detailing build, manufacturing, and flight-test processes.
2026-08-10 Create printing
2026-08-10 Enhance 3D Printing section with details and link
    Updated the 3D Printing & Manufacturing section to include detailed part-level manufacturing records and an active link to the printing report.
    Activate Stallion V2 Build 01 printing report link
2026-08-12 Remove accidentally uploaded root files
    [Split Rear Motor Mount.stl, VTail Left Modified.stl, VTail Right Modified.stl]
2026-08-12 Remove obsolete Super Stingray printing folder
2026-08-12 Update Super Stingray VTOL printing report
2026-08-13 Document hardened steel nozzle in printing reports
2026-08-13 Added hyperlink for hardened steel nozzle in printing reports
2026-08-13 Updated 3D printing inventory
2026-08-16 Move Stallion hero image into assets folder
2026-08-17 Super Stingray VTOL printing updates
